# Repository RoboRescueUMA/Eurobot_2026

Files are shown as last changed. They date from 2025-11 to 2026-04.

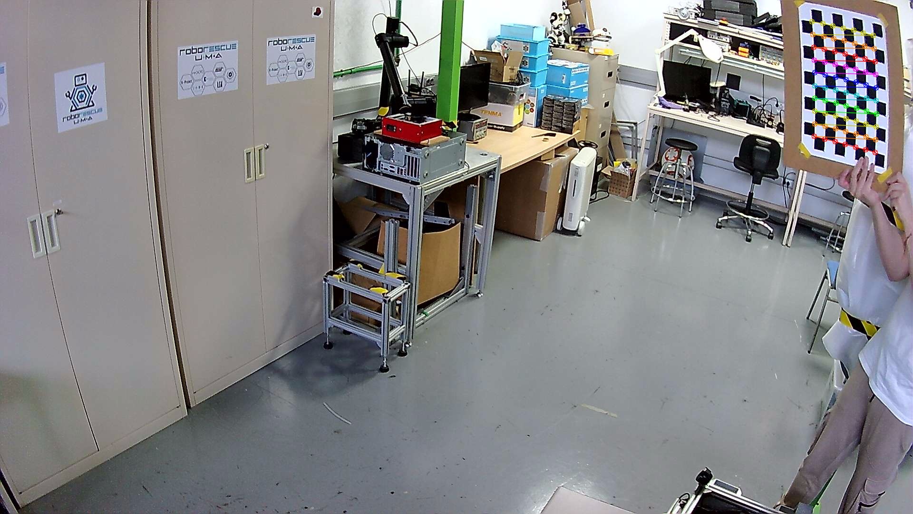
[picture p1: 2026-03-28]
Software/Visión Arucos/fotos_calibracion_detectadas2/foto_037.jpg

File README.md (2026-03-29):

# 🤖 Eurobot 2026 — RoboRescue Team

Repositorio oficial del equipo **RoboRescue** para la competición **Eurobot 2026**.

---

## 🧠 ¿Qué es Eurobot?

**Eurobot** es una competición internacional de robótica donde equipos diseñan, construyen y programan robots autónomos capaces de realizar tareas en un entorno de juego específico.

Cada año, la competición propone un nuevo desafío con reglas propias, donde los robots deben:
* Actuar de forma completamente autónoma
* Interactuar con elementos del entorno
* Competir contra otro robot en tiempo real
* Maximizar la puntuación en un tiempo limitado

---
## 🧊 Eurobot 2026 — “Winter is Coming”
El objetivo general del juego es ayudar a unas ardillas a recuperar y proteger sus bellotas antes de que vuelvan los humanos, gestionando misiones como recuperar 
cajas, controlar condiciones ambientales o devolverlas a sus nidos antes de tiempo.

* Para más información sobre la competicion leer --> Reglamento / EurobotSenior_General.pdf

---

## 🧩 Estructura del Repositorio

El proyecto está organizado en varios módulos principales:

```
📂 Eurobot_2026
├── ⚙️ hardware/                           # Diseño mecánico y 3D, esquemas electrónicos y slprt de componentes
├── 🧠 software/                           # Código del robot (ROS2, control, visión, etc.)
├── 📄 reglamento/                         # Documentación técnica
└── 📦 documentos de referencia/           # Documentos que pueden ser de ayuda
```

---

## ⚙️ Arquitectura del Sistema

El robot sigue una arquitectura distribuida:

### 🔹 Nivel Alto (Computación)

* Procesamiento de visión
* Planificación de trayectoria
* Toma de decisiones

### 🔹 Nivel Bajo (Control en Tiempo Real)

* Lectura de sensores
* Control de motores

### 🔹 Comunicación

* Middleware basado en **ROS 2**
* Intercambio de datos entre nodos

---

## 🚀 Tecnologías Utilizadas

* **ROS 2** → Comunicación entre nodos
* **Python / C++** → Desarrollo de software
* **ESP32** → Control de hardware
* **OpenCV** → Visión artificial
* **CAD (SolidWorks)** → Diseño mecánico

---

## 🏁 Estado del Proyecto

🚧 En desarrollo — Temporada Eurobot 2026

---

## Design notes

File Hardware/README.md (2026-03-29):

# 🤖 Eurobot 2026 — Hardware & Design

Aquí se centralizan todos los archivos de **diseño físico**, **electrónica** y **modelado 3D** del robot para la competición **Eurobot 2026**.

---

## 📂 Estructura del Repositorio

La sección de Hardware se divide en **tres pilares fundamentales**:

---

### ⚙️ 1. Componentes

Contiene las librerías de piezas individuales y activos estándar utilizados en el ensamblaje.

| 🔧 Categoría  | 📦 Contenido |
| --- | --- |
| 🤖 Motores | Modelos y soportes para **Servos**, motores y sistemas de garras |
| 📡 Sensores | Archivos para **HC-SR04** y **RPLidar C1** |
| 🧠 Control | Modelos de **Raspberry Pi** |
| 📦 Miscelánea | Baterías, rodamientos, microswitches y otros componentes auxiliares |

---

### ⚡ 2. Electrónica

Aquí se encuentra toda la electrónica y la distribución de potencia del robot.

| ⚡ Sección | 📄 Contenido |
| --- | --- |
| 🧩 Esquemas KiCad | Archivos del diseño eléctrico listo para modificarlo |
| 🔌 Esquema eléctrico | Referencia rápida del cableado y conexionado en formato PDF |

---

### 🏗️ 3. Modelos 3D

Ensamblajes principales y diseños mecánicos complejos del robot.

| 🏗️ Categoría | 📦 Contenido |
| --- | --- |
| 🚗 Chasis | Diseños del **Chasis** del Robot |
| 🦾 Mecanismos | Diseño de la **Garra** y sistema de elevación |
| 📦 Cajas | Diseños como **CajaBellota** |

---

## 🛠️ Herramientas Utilizadas

| 🧰 Tipo | 🔧 Herramientas |
| --- | --- |
| 🧱 CAD  | SolidWorks (`.SLDPRT`, `.SLDASM`) + formatos `.STEP` |
| ⚡ EDA | KiCad (diseño de circuitos impresos) |

---

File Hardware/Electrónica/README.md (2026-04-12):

# 🤖 Eurobot 2026 — Arquitectura Electrónica

**Diseño eléctrico, esquemas y documentación técnica** del sistema electrónico del robot desarrollado para la competición **Eurobot 2026**.

---

## 🧠 Arquitectura del Sistema

El robot implementa una **arquitectura híbrida de procesamiento**, donde la inteligencia de alto nivel y el control en tiempo real están separados para lograr robustez, velocidad y modularidad:

### 🔹 Nivel Superior — Visión & Estrategia

* **Raspberry Pi**
* Ejecuta:

  * Visión artificial
  * Planificación de alto nivel
  * Lógica de misión
  * Comunicación con sistemas de percepción

### 🔹 Nivel de Control — Tiempo Real & Actuación

* **ESP32**
* Responsable de:

  * Control de motores
  * Control de servos
  * Lectura de sensores
  * Odometría

### 🔗 Comunicación entre controladores

* Conexión **Serial / UART (TX-RX) por cable**
* Permite:

  * Baja latencia
  * Mayor robustez ante interferencias
  * Sin dependencias de red inalámbrica

---

## 🛠️ Componentes Principales

| Ítem | Componente | Cantidad | Función |
| ---- | --- | --- | --- |
| 1 | ESP32 | 1 | Control en tiempo real |
| 2 | Raspberry Pi 5 | 1 | Visión y lógica de misión |
| 3 | Driver Puente H DRI0002 | 2 | Control de motores DC |
| 4 | Motor DC + Encoder | 4 | Tracción y odometría |
| 5 | Regulador LM2596 | 1 | Conversión 12V → 5V |
| 6–8  | Servomotores | 3 | FT5335M, HS-331, sg90 |
| 10 | Seta de emergencia | 1 | Parada inmediata del sistema |

---

## 📐 Esquema Eléctrico

El diseño se ha realizado en **KiCad 9.0.6**.

* Entrada principal desde batería **12V nominal (≈11.6V real)**

---

## 🔌 Asignación de Pines — ESP32

### 🏎️ Tracción (Drivers)

| Pines ESP32 | Función | Motor / Driver |
| --- | --- | --- |
| 27 / 14 | PWM / DIR | Delantero Izquierdo (DR1) |
| 25 / 26 | PWM / DIR | Delantero Derecho (DR1) |
| 32 / 33 | PWM / DIR | Trasero Izquierdo (DR2) |
| 18 / 19 | PWM / DIR | Trasero Derecho (DR2) |

---

### 📊 Odometría (Encoders)

| Pines ESP32 | Canal | Encoder |
| --- | ----- | --- |
| 21 / 22 | A / B | Delantero Izquierdo |
| 34 / 35 | A / B | Delantero Derecho |
| 16 / 17 | A / B | Trasero Izquierdo |
| 23 / 4 | A / B | Trasero Derecho |

---

### 🦾 Manipulación (Servos)

| Pin Raspberry | Nombre GPIO |Elemento |
| --- | --- | --- |
| 12 | GPIO 18 | Servo 1 |
| 32 | GPIO 12 | Servo 2 |
| 33 | GPIO 13 | Servo 3 |
| 14 (o cualquier GND) | Ground | Tierra
| No Usado  | Input | Encoder Feedback Elevación |
| ND. | ND. | Microswitch detección piezas|

---

## 🏁 Arranque (microswitch)

| Pines Raspberry | 
| -----------  |
| ND      |
| GND     |

---

## 🛡️ Seguridad y Operación

* 🛑 **Parada de emergencia** mediante seta física que corta alimentación general.
* 🧵 **Arranque con cuerda** para iniciar el ciclo de competición.

---

> ⚡ Este repositorio es parte del desarrollo del robot para la competición Eurobot 2026.

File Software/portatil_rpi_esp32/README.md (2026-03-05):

# Robot Eurobot 2026 - Equipo RoboRescue

Proyecto de robot autónomo para la competición **Eurobot 2026** - Categoría Senior.

**Equipo:** RoboRescue

---

## Descripción del Proyecto

Este proyecto implementa un robot autónomo con arquitectura distribuida para competir en Eurobot 2026. El sistema está dividido en tres componentes principales:

- **Portátil**: Procesamiento intensivo de visión por computadora
- **Raspberry Pi 4**: Coordinación, navegación y control de alto nivel
- **ESP32**: Control de bajo nivel de motores y actuadores

### Características Principales

- 🤖 Robot con **ruedas Mecanum** para movimiento omnidireccional
- 👁️ **Sistema de visión distribuida** con detección de **ArUco markers**
- 🎯 **Navegación autónoma** con control proporcional
- 🔗 Comunicación distribuida mediante **ROS2 Humble**
- ⚡ Control de motores con **micro-ROS** en ESP32
- 📍 Localización precisa mediante cámara zenital (IP Camera)
- 🔄 **Arquitectura de 3 capas:** Laptop (visión) → RPI4 (relay) → ESP32 (motores)

---

## Estructura del Proyecto

```
laptop_rpi_esp/
├── docs/                         # Documentación del proyecto
│   ├── guias/                   # Guías de uso
│   │   ├── GUIA_VISION_DISTRIBUIDA.md    # Sistema de visión con ArUco
│   │   ├── GUIA_PRUEBAS_ROBOT.md         # Comandos de prueba
│   │   └── INSTALACION_DEPENDENCIAS.md   # Dependencias externas
│   ├── troubleshooting/         # Solución de problemas
│   │   ├── encoders.md          # Problemas con encoders
│   │   ├── micro-ros.md         # Problemas con micro-ROS
│   │   ├── esp32-flash.md       # Problemas subiendo código a ESP32
│   │   └── motores.md           # Problemas con motores
│   ├── hardware/                # Especificaciones técnicas
│   │   ├── ESPECIFICACIONES_HARDWARE.md
│   │   └── CONEXION_ENCODERS.md
│   ├── architecture/            # Diagramas de arquitectura
│   │   └── ARQUITECTURA_SISTEMA.md
│   └── reglamento/              # Reglamento oficial Eurobot 2026
│       ├── EurobotSenior_general.pdf
│       ├── Arena y puntuaciones.pdf
│       └── RESUMEN_REGLAMENTO.md
├── src/                         # Paquetes ROS2
│   ├── robot_localization/     # 🆕 Localización + Navegación (Laptop)
│   │   ├── robot_localization/
│   │   │   ├── camera_publisher.py        # Captura de cámara IP cenital
│   │   │   ├── field_localizer.py         # Detección ArUco + Homografía (poses absolutas)
│   │   │   └── aruco_navigator.py (futura) # Navegación en campo (por implementar)
│   │   ├── launch/
│   │   │   └── robot_localization.launch.py
│   │   ├── config/
│   │   │   └── robot_localization.yaml
│   │   ├── package.xml
│   │   └── setup.py
│   ├── laptop_vision/          # (Antiguo - mantener como referencia histórica)
│   │   └── (código anterior de visión relativa)
│   ├── rpi_relay/              # 🆕 Relay de comandos (RPI4)
│   │   └── cmd_vel_relay.py         # Reenvía /roborescue/cmd_vel_laptop → /roborescue/cmd_vel
│   ├── robot_vision/           # (Antiguo - backup)
│   ├── robot_navigator/        # (Antiguo - backup)
│   └── interfaces/             # Mensajes y servicios personalizados (TODO)
├── esp32_roborescue/           # ESP32 robot competición (DFRobot drivers)
│   ├── src/main.cpp            # Control Mecanum con PWM+DIR
│   └── README.md               # Documentación específica
├── esp32_casa/                  # ESP32 robot pruebas (L298N drivers)
│   ├── src/main.cpp            # Control Mecanum con IN1/IN2+EN
│   └── README.md               # Documentación específica
├── config/                      # Archivos de configuración
├── launch/                      # Launch files centralizados
└── README.md                    # Este archivo
```

---

## Requisitos del Sistema

### Hardware

- **Portátil** con WiFi (Ubuntu 22.04 recomendado)
- **Raspberry Pi 4** (4GB RAM o superior)
- **ESP32** (DevKit o similar)
- **4x Motores DC** con encoders y reductora
- **2x Puentes H** (drivers DFRobot o equivalentes)
- **4x Ruedas Mecanum** (omni-direccionales)
- **Cámara IP** (WiFi/Ethernet, HD)
- **Marcadores ArUco** (DICT_4X4_50)
- Batería LiPo con protección (máx. 48V según reglamento)

### Software

- **ROS2 Humble** (Ubuntu 22.04)
- **Python 3.10+** con OpenCV, NumPy
- **PlatformIO** (para ESP32)
- **micro-ROS** (para comunicación ESP32-ROS2)

### Configuración del Sistema

- **ROS_DOMAIN_ID:** 17 (evita conflictos con otros robots)
- **Namespace:** `roborescue`
- **Cámara IP:** `10.16.250.84:5000`
- **Sistema de Localización:** Homografía con 4 ArUcos fijos en esquinas del campo
- **ArUco IDs (Fijos - Campo):**
  - Esquina sup-izq: 20 → (0, 0) cm
  - Esquina sup-der: 21 → (300, 0) cm
  - Esquina inf-izq: 22 → (0, 200) cm
  - Esquina inf-der: 23 → (300, 200) cm
- **ArUco IDs (Móviles):**
  - Robot: 1
  - Caja azul: 36
  - Caja amarilla: 47
- **Diccionario ArUco:** DICT_4X4_50
- **Tamaño campo:** 300 cm × 200 cm (Eurobot 2026)

### Parámetros de Navegación (Actuales)

- **max_linear_speed:** 0.25 m/s
- **max_angular_speed:** 0.5 rad/s
- **linear_p_gain:** 2.5 (necesario para generar velocidad > PWM_MIN)
- **angular_p_gain:** 0.6
- **Histéresis angular:**
  - Umbral entrar: 20° (entra en modo rotación)
  - Umbral salir: 10° (sale de modo rotación)
- **goal_tolerance:** 0.20 m (distancia de parada al objetivo)
- **PWM_MIN:** 80 (~0.31 m/s - necesario para vencer fricción estática)
- **Encoders:** Habilitados (11 PPR motor × 34 reducción = 374 PPR rueda, cuadratura ×4 = 1496 counts/rev)

---

## Instalación

### 1. Configurar ROS2 Workspace (Portátil y Raspberry Pi)

```bash
# Instalar ROS2 Humble (si no está instalado)
# Ver: https://docs.ros.org/en/humble/Installation.html

# Clonar el repositorio
cd ~/Desktop/GitHub
git clone <URL_DEL_REPOSITORIO> pruebas_eurobot
cd pruebas_eurobot

# Instalar dependencias de Python y OpenCV
sudo apt update
sudo apt install python3-pip python3-opencv ros-humble-cv-bridge

# Instalar dependencias de Python adicionales
pip3 install opencv-python numpy

# Compilar workspace
colcon build --packages-select laptop_vision rpi_relay
source install/setup.bash
```

**Nota:** Ver `docs/guias/INSTALACION_DEPENDENCIAS.md` para detalles completos de todas las dependencias externas.

### 2. Configurar micro-ROS en Raspberry Pi

#### Opción A: Instalar micro-ROS Agent (solo agent)

```bash
# Instalar micro-ROS agent desde paquetes binarios
sudo apt install ros-humble-micro-ros-agent

# Ejecutar agent (ajustar puerto serial)
ros2 run micro_ros_agent micro_ros_agent serial --dev /dev/ttyUSB0 -b 115200
```

#### Opción B: Compilar micro_ros_setup (completo, requerido para desarrollo ESP32)

```bash
# Crear workspace separado para micro-ROS
mkdir -p ~/ros2_ws/src
cd ~/ros2_ws/src

# Clonar micro_ros_setup
git clone -b humble https://github.com/micro-ROS/micro_ros_setup.git

# Compilar
cd ~/ros2_ws
colcon build --packages-select micro_ros_setup
source install/setup.bash

# Ejecutar agent
ros2 run micro_ros_agent micro_ros_agent serial --dev /dev/ttyUSB0 -b 115200
```

**Importante:** Si vas a compilar firmware para ESP32, necesitas usar la Opción B.

### 3. Flashear ESP32 (desde cualquier máquina con PlatformIO)

#### Robot RoboRescue (Universidad - Competición):
```bash
cd esp32_roborescue/
# Editar platformio.ini si es necesario
pio run --target upload
```

#### Robot Casa (Pruebas personales):
```bash
cd esp32_casa/
# Editar platformio.ini si es necesario
pio run --target upload
```

**Nota:** Ver README.md en cada carpeta ESP32 para detalles específicos de hardware.

---

## Uso

### Sistema de Localización y Navegación (NUEVO - Recomendado)

Este es el sistema actual que implementa **localización absoluta en el campo** mediante homografía con 4 ArUcos fijos en las esquinas, seguida de **navegación autónoma** hacia objetivos.

#### En Portátil (Sistema de Localización):

```bash
cd ~/Desktop/GitHub/pruebas_eurobot
source install/setup.bash

# IMPORTANTE: Configurar ROS_DOMAIN_ID=17
export ROS_DOMAIN_ID=17

# Lanzar: Publicador de cámara IP + Localizador de campo con homografía
ros2 launch robot_localization robot_localization.launch.py \
  camera_ip:=10.16.250.84:5000

# Ver imagen con detecciones en tiempo real
ros2 run rqt_image_view rqt_image_view /roborescue/zenital/debug
```

**Ver:** `docs/guias/GUIA_ROBOT_LOCALIZATION.md` para guía detallada de la homografía y localización absoluta.

#### En Raspberry Pi 4 (Relay + micro-ROS):

```bash
cd ~/Desktop/GitHub/pruebas_eurobot
source install/setup.bash

# IMPORTANTE: Configurar ROS_DOMAIN_ID=17
export ROS_DOMAIN_ID=17

# Terminal 1: Micro-ROS Agent (comunicación con ESP32)
ros2 run micro_ros_agent micro_ros_agent serial --dev /dev/ttyUSB0 -b 115200

# Terminal 2: Relay de comandos (reenvía /roborescue/cmd_vel_laptop → /roborescue/cmd_vel)
ros2 run rpi_relay cmd_vel_relay
```

---

### Sistema Anterior - Visión Relativa (Backup)

#### 📍 Marcadores ArUco - Configuración Nuevo Sistema

El sistema de localización detecta posiciones **absolutas en el campo** usando 4 ArUcos fijos como referencia.

**Marcadores fijos (esquinas del campo):**
- **ID=20** - Esquina superior-izquierda (origen: 0, 0 cm)
- **ID=21** - Esquina superior-derecha (300, 0 cm)
- **ID=22** - Esquina inferior-izquierda (0, 200 cm)
- **ID=23** - Esquina inferior-derecha (300, 200 cm)

**Marcadores móviles:**
- **ID=1** - Robot (se detecta en coordenadas absolutas del campo)
- **ID=36** - Caja azul (coordenadas absolutas)
- **ID=47** - Caja amarilla (coordenadas absolutas)

**Colocación correcta:**

1. **Los 4 ArUcos fijos** deben estar colocados en las esquinas del campo de forma que:
   - El área vista por la cámara zenital es la del campo (300×200 cm)
   - Los 4 ArUcos están claramente visibles desde el inicio

2. **El ArUco del robot (ID=1)** debe estar:
   - Alineado de forma que su esquina 0 apunte hacia **adelante del robot**
   - Esto se visualiza en el debug como una flecha/círculo rojo que marca la dirección
   - La orientación se publica en `theta` (en grados) del topic `/roborescue/robot_pose`

**Verificación:**
- En la imagen debug (`/roborescue/zenital/debug`), deberías ver:
  - Los 4 ArUcos fijos etiquetados como "F20", "F21", "F22", "F23"
  - El ArUco del robot etiquetado como "ROBOT" con posición en cm y ángulo
  - Las cajas etiquetadas como "AZUL" y "AMARILLA" con posiciones absolutas

---

### Sistema Anterior (Backup)

Los paquetes `laptop_vision`, `robot_vision` y `robot_navigator` son versiones anteriores del sistema que usaban **visión relativa** (posiciones relativas al robot, no absolutas en el campo).

#### En Raspberry Pi 4:

```bash
# Terminal 1: Micro-ROS Agent
ros2 run micro_ros_agent micro_ros_agent serial --dev /dev/ttyUSB0

# Terminal 2: Navegación y control
ros2 launch robot_navigator eurobot_launch.py
```

#### En Portátil:

```bash
# Terminal 1: Procesamiento de visión
ros2 launch laptop_vision laptop_vision.launch.py camera_ip:=10.16.250.84:5000 target:=blue_box

# Terminal 2: Monitoreo (opcional)
ros2 run rqt_image_view rqt_image_view
```

---

### Verificar Comunicación

```bash
# Ver topics activos
ros2 topic list

# Monitorear comandos de velocidad
ros2 topic echo /roborescue/cmd_vel

# Ver posiciones ABSOLUTAS detectadas (nuevo sistema)
ros2 topic echo /roborescue/robot_pose         # X, Y en cm, theta en grados
ros2 topic echo /roborescue/blue_box_pose
ros2 topic echo /roborescue/yellow_box_pose

# Ver imágenes procesadas
ros2 run rqt_image_view rqt_image_view /roborescue/zenital/debug
```

---

### Verificar Encoders

```bash
# Ver velocidades de encoders (FL, FR, RL, RR en RPM)
export ROS_DOMAIN_ID=17
ros2 topic echo /roborescue/encoder_velocities
```

**Ver guía completa de pruebas:** `docs/hardware/CONEXION_ENCODERS.md`  
**Troubleshooting:** `docs/troubleshooting/encoders.md`

---

## Arquitectura del Sistema

```
┌─────────────────────────────────────────────────────────────────────────────┐
│                    ARQUITECTURA DISTRIBUIDA - 3 CAPAS                        │
└─────────────────────────────────────────────────────────────────────────────┘

  ┌─────────────────────┐        ┌─────────────────────┐        ┌──────────────────┐
  │   PORTÁTIL (WiFi)   │        │   RPI4 (Ethernet)   │        │  ESP32 (Serial)  │
  │                     │        │                     │        │                  │
  │  robot_localization │        │   rpi_relay         │        │  micro-ROS       │
  │  ├─ camera_pub      │        │   ├─ cmd_vel_relay  │        │  ├─ Cinemática   │
  │  └─ field_local     │        │   │    (relay with   │        │  │   Mecanum      │
  │     (homografía     │        │   │    namespace)    │        │  └─ Control PWM  │
  │      poses abs)     │  ROS2  │   └─────────┬───────┼────────┼──────PWM_MIN=80──►
  │                     │  WiFi  │             │       │ Serial │                  │
  │  Publicadores:      │  DDS   │  /roborescue│       │ micro- │   Suscriptor:    │
  │  /roborescue/       │        │  /cmd_vel_  │       │  ROS   │  /roborescue/    │
  │    zenital/*        │        │   laptop    │       │        │    cmd_vel       │
  │  /roborescue/       │        │      ↓      │       │        │                  │
  │    *_pose (ABS)     │        │  /roborescue│       │        │                  │
  │  /roborescue/       │        │   /cmd_vel  │       │        │                  │
  │    cmd_vel_laptop   │        └─────────────┘       │        └────────┬─────────┘
  └──────────┬──────────┘        └─────────────┘       │                 │
             │                                         │                 │
      Cámara IP (móvil)                         micro_ros_agent    4x Motores DC
      Homografía + ArUcos                       (ROS2↔micro-ROS)   + 2x Drivers
      (10.16.250.84:5000)                       bridge process     (Ruedas Mecanum)

NUEVO: Coordenadas ABSOLUTAS del campo (cm)
       - Origen: esquina sup-izq (ArUco 20)
       - X+ = derecha, Y+ = abajo
       - 4 ArUcos fijos en esquinas (IDs 20-23)
```

### Flujo de Datos Completo

1. **Cámara IP** (móvil con IPCamera app) → Stream video vía WiFi
2. **Portátil** recibe stream → `camera_publisher` publica en `/roborescue/zenital/image_raw`
3. **Portátil** `field_localizer` (NUEVO):
   - Detecta los 4 ArUcos fijos en las esquinas (IDs 20-23)
   - Calcula homografía píxeles → cm del campo
   - Transforma posiciones de robot y cajas a coordenadas ABSOLUTAS del campo
4. **Portátil** publica poses ABSOLUTAS:
   - `/roborescue/robot_pose` → X, Y en cm, theta en grados
   - `/roborescue/blue_box_pose`, `/roborescue/yellow_box_pose`
5. **Portátil** `aruco_navigator` (por implementar) → Recibirá poses absolutas, calculará velocidades
6. **Portátil** publica comandos → `/roborescue/cmd_vel_laptop` (Twist)
7. **RPI4** `cmd_vel_relay` reenvía → `/roborescue/cmd_vel_laptop` → `/roborescue/cmd_vel`
8. **ESP32** recibe vía micro-ROS → `/roborescue/cmd_vel` (Twist)
9. **ESP32** calcula cinemática inversa → Velocidades individuales de 4 ruedas Mecanum
10. **ESP32** envía PWM → 4 motores DC → Robot se mueve

### Topics ROS2 Principales

**Laptop publica (robot_localization):**
- `/roborescue/zenital/image_raw` - Video cámara (Image)
- `/roborescue/zenital/image_raw/compressed` - Video comprimido (CompressedImage)
- `/roborescue/zenital/debug` - Video con anotaciones (Image)
- `/roborescue/robot_pose` - **Posición ABSOLUTA en cm + orientación en grados** (Pose2D: x, y, theta)
- `/roborescue/blue_box_pose` - **Posición ABSOLUTA en cm + orientación** (Pose2D)
- `/roborescue/yellow_box_pose` - **Posición ABSOLUTA en cm + orientación** (Pose2D)
- `/roborescue/cmd_vel_laptop` - Comandos de velocidad (Twist) [por implementar: aruco_navigator]

**RPI4 relay:**
- Suscribe: `/roborescue/cmd_vel_laptop` (Twist)
- Publica: `/roborescue/cmd_vel` (Twist) - Para ESP32 vía micro-ROS

**ESP32 suscribe:**
- `/roborescue/cmd_vel` (Twist) - Velocidades lineales (x, y) y angular (z)

---

## Documentación Adicional

### Documentación Adicional

### Documentación del Sistema

- 📍 [**Guía de Localización Absoluta (Homografía)**](docs/guias/GUIA_ROBOT_LOCALIZATION.md) - **NUEVO**: Sistema con coordenadas absolutas del campo
- 👁️ [**Guía del Sistema de Visión Distribuida**](docs/guias/GUIA_VISION_DISTRIBUIDA.md) - Sistema anterior (visión relativa)
- 📦 [**Instalación de Dependencias**](docs/guias/INSTALACION_DEPENDENCIAS.md) - Guía completa de dependencias externas
- 🧪 [**Guía de Pruebas**](docs/guias/GUIA_PRUEBAS_ROBOT.md) - Comandos de prueba para Robot Casa y RoboRescue
- 🔧 [**Troubleshooting**](docs/troubleshooting/) - Problemas comunes y soluciones por categoría
  - [Encoders](docs/troubleshooting/encoders.md)
  - [micro-ROS](docs/troubleshooting/micro-ros.md)
  - [ESP32 Flash](docs/troubleshooting/esp32-flash.md)
  - [Motores](docs/troubleshooting/motores.md)

### Documentación del Proyecto

- 📖 [Resumen del Reglamento Eurobot 2026](docs/reglamento/RESUMEN_REGLAMENTO.md)
- 🔩 [Especificaciones de Hardware](docs/hardware/ESPECIFICACIONES_HARDWARE.md)
- 🏗️ [Arquitectura del Sistema](docs/architecture/ARQUITECTURA_SISTEMA.md)

### Documentación del Hardware

- 🤖 [ESP32 RoboRescue](esp32_roborescue/README.md) - Robot de competición (DFRobot drivers)
- 🏠 [ESP32 Casa](esp32_casa/README.md) - Robot de pruebas (L298N drivers)

---

## Calendario y Tareas Pendientes

### Fechas Importantes (Verificar con organizador)

- ✅ Inscripción del equipo
- ⚠️ **Logo del equipo** - Fecha límite: TBD
- ⚠️ **Video de presentación** - Fecha límite: 10 de Febrero
- ⚠️ **Homologación del robot** - Fecha límite: 1 de Marzo
- ⚠️ **Póster técnico y presentación** - Fecha límite: 1 de Marzo
- 🎯 **Robot montado (hardware)** - Fecha límite: 20 de Febrero
- 🎯 **Software básico funcional** - Fecha límite: 15 de Marzo
- 🎯 **Pruebas en escenario** - Fecha límite: 15 de Abril
- 🏁 **Competición Nacional** - Abril 2026

### Próximos Pasos Técnicos

#### ✅ Completados

- [x] **Sistema de visión distribuida funcional** - Laptop (visión) → RPI4 (relay) → ESP32 (motores)
- [x] **Detección de ArUco markers** - DICT_4X4_50 con auto-calibración de escala
- [x] **Navegación autónoma básica** - Control proporcional hacia cajas azul/amarilla (ambas probadas)
- [x] **Timeout de seguridad** - Robot se detiene automáticamente sin detección (1s)
- [x] **Cámara IP funcional** - Streaming desde móvil con app IPCamera
- [x] **Namespace correcto en ROS2** - Topics organizados bajo `/roborescue/`
- [x] **Comunicación RPI ↔ Laptop** - ROS2 DDS sobre WiFi/Ethernet
- [x] **Relay de comandos en RPI** - `/roborescue/cmd_vel_laptop` → `/roborescue/cmd_vel`
- [x] **Conexión ESP32 ↔ RPI (micro-ROS)** - Serial /dev/ttyUSB0 con namespace funcionando
- [x] **Integración completa 3 capas** - Sistema end-to-end probado exitosamente
- [x] **Control de motores desde visión** - Robot se mueve según detección ArUco
- [x] **Calibración PWM para fricción** - PWM_MIN=80 permite vencer fricción estática
- [x] **Inversión de coordenadas 180°** - Sistema funciona con cámara rotada 180°
- [x] **Movimiento omnidireccional** - Navegación con strafing lateral funcional
- [x] **Ajuste de ganancias proporcionales** - linear_p_gain=2.5, angular_p_gain=0.6

#### 🔄 En Progreso

- [ ] **Implementar aruco_navigator dentro de robot_localization** - Navegación hacia objetivos usando poses absolutas
- [ ] **Pruebas en arena de competición** - Validar navegación en superficie plana de competencia
- [ ] **Filtrado de posiciones ArUco** - Aplicar promedio móvil para reducir jitter de detección

#### 📋 Pendientes

- [ ] **Mejorar cálculo de distancia** - Usar distancia 2D proyectada (ignorar diferencia de altura ArUco)
- [ ] **Optimizar control cerca del objetivo** - Reducir PWM_MIN o implementar mapeo proporcional
- [ ] **Control PID completo** - Añadir términos I y D para mejor estabilidad

---

## Referencias del Proyecto Antiguo

El código base proviene de proyectos anteriores:

- **ROS2 Workspace:** `/home/maki/Desktop/rpi_casa/src/`
  - `robot_vision/` - Detección ArUco y seguimiento
  - `robot_navigator/` - Control de navegación
  
- **ESP32 micro-ROS:** `/home/maki/Documents/PlatformIO/Projects/microros_esp_eurobot/`
  - Control de motores Mecanum funcional

---

## Contribuir

Este es un proyecto de equipo para Eurobot 2026.

### Workflow de Desarrollo

1. Crear rama para nueva funcionalidad: `git checkout -b feature/nombre`
2. Desarrollar y probar localmente
3. Commit con mensajes descriptivos
4. Push y crear pull request para revisión
5. Integrar tras aprobación del equipo

---

## Recursos Externos

- 🌐 [Sitio oficial Eurobot](https://www.eurobot.org/)
- 📚 [FAQ Eurobot](https://www.eurobot.org/faq/)
- 📧 Comité de árbitros: referee@eurobot.org
- 🤖 [Documentación ROS2 Humble](https://docs.ros.org/en/humble/)
- 🔌 [micro-ROS Documentation](https://micro.ros.org/)

---

## Licencia

Por definir por el equipo.

---

## Equipo

**Nombre del equipo:** RoboRescue  
**Año:** 2026  
**Categoría:** Senior

**Miembros:**
- [Completar]

---

## Robots del Proyecto

### Robot RoboRescue (Universidad - Competición)
- **Ubicación código:** `esp32_roborescue/`
- **Hardware:** 4x Ruedas Mecanum + 2x DFRobot drivers
- **Estado:** Listo para competición
- **Uso:** Eurobot 2026 oficial

### Robot Casa (Pruebas personales)
- **Ubicación código:** `esp32_casa/`
- **Hardware:** Preparado para Mecanum + 2x L298N drivers
- **Estado:** En desarrollo
- **Uso:** Pruebas y desarrollo de software

---

**Última actualización:** Febrero 18, 2026

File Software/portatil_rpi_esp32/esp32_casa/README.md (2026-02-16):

# ESP32 - Robot de Pruebas (Casa)

## Descripción
Este es el código para el **robot de pruebas personal** con ruedas preparadas para Mecanum.

---

## Características del Robot

### Hardware
- **Ruedas:** Preparado para 4x Mecanum (código listo aunque aún sin ruedas físicas)
- **Configuración:** X-Drive
- **Drivers:** 2x L298N (puente H clásico)
- **Control:** IN1/IN2/IN3/IN4 (dirección) + ENA/ENB (velocidad PWM)

### Especificaciones Técnicas
- **Movimiento:** Omnidireccional cuando tengas las ruedas Mecanum
- **Control:** Via micro-ROS (igual que RoboRescue)
- **Topic:** `/cmd_vel` (geometry_msgs/Twist)

---

## Configuración de Pines

### Driver 1 (Trasero) - L298N

| Motor | Ubicación | ENA/ENB | IN1 | IN2 | Canal PWM |
|---|---|---|-----|-----|---|
| M0 | Trasero Izquierda | GPIO32 | GPIO33 | GPIO25 | Canal 0 |
| M1 | Trasero Derecha | GPIO14 | GPIO26 | GPIO27 | Canal 1 |

### Driver 2 (Frontal) - L298N

| Motor | Ubicación | ENA/ENB | IN1 | IN2 | Canal PWM |
|---|---|---|-----|-----|---|
| M2 | Frontal Izquierda | GPIO15 | GPIO2 | GPIO4 | Canal 2 |
| M3 | Frontal Derecha | GPIO5 | GPIO18 | GPIO19 | Canal 3 |

**Nota:** Motor 3 usa GPIO18/19 (antes 16/17) para evitar conflictos con UART2.

---

## Lógica de Control

### Driver L298N (IN1/IN2 + EN)

```cpp
// Para cada motor:
IN1=HIGH, IN2=LOW → Adelante
IN1=LOW, IN2=HIGH → Atrás
IN1=LOW, IN2=LOW → Freno
ENA/ENB (PWM 0-255) → Velocidad
```

### Cinemática Mecanum (X-Drive)

```cpp
// Mismo algoritmo que RoboRescue
// Entradas: vx, vy, wz
fl = vx - vy - wz  // Frontal Izquierda (M2)
fr = vx + vy + wz  // Frontal Derecha (M3)
rl = vx + vy - wz  // Trasera Izquierda (M0)
rr = vx - vy + wz  // Trasera Derecha (M1)
```

---

## Diferencias con RoboRescue

| Característica | RoboRescue (Universidad) | Casa (Pruebas) |
|---|---|---|
| Driver | DFRobot (PWM+DIR) | L298N (IN1/IN2+EN) |
| Pines por motor | 2 (PWM, DIR) | 3 (IN1, IN2, EN) |
| Lógica control | DIR=HIGH→Adelante | IN1=HIGH,IN2=LOW→Adelante |
| Ruedas físicas | ✅ Mecanum instaladas | ⚠️ Pendiente de instalar |

---

## Compilar y Flashear

```bash
cd ~/Desktop/laptop_rpi_esp/esp32_casa
pio run --target upload
```

### Monitor Serial

```bash
pio device monitor
```

---

## Conectar con ROS2

### Desde tu portátil o RPI:

```bash
# Importante: Configurar Domain ID 17
export ROS_DOMAIN_ID=17

# Iniciar micro-ROS agent
ros2 run micro_ros_agent micro_ros_agent serial --dev /dev/ttyUSB0 -b 115200
```

### Probar movimiento:

```bash
# IMPORTANTE: Los comandos van al namespace roborescue
export ROS_DOMAIN_ID=17

# Mover adelante
ros2 topic pub /roborescue/cmd_vel geometry_msgs/Twist "{linear: {x: 0.3, y: 0.0, z: 0.0}, angular: {x: 0.0, y: 0.0, z: 0.0}}"

# Mover lateral (Mecanum)
ros2 topic pub /roborescue/cmd_vel geometry_msgs/Twist "{linear: {x: 0.0, y: 0.3, z: 0.0}, angular: {x: 0.0, y: 0.0, z: 0.0}}"

# Girar
ros2 topic pub /roborescue/cmd_vel geometry_msgs/Twist "{linear: {x: 0.0, y: 0.0, z: 0.0}, angular: {x: 0.0, y: 0.0, z: 0.5}}"
```

---

## Seguridad

### Zona Muerta
- PWM < 20 → PWM = 0 (evita zumbidos y sobrecalentamiento)

### Nodo micro-ROS
- Nombre del nodo: `esp32_casa_mecanum`
- Namespace: `roborescue`
- Domain ID: `17`
- Suscripción: `/roborescue/cmd_vel`
- Watchdog: Parada automática tras 0.5s sin comandos

---

## Notas Importantes

- ⚠️ **El código está preparado para Mecanum** pero funcionará con ruedas normales (solo se ignorará el movimiento lateral)
- Cuando instales las ruedas Mecanum, el código ya está listo para usarlas sin cambios
- Si tienes problemas con los pines, verifica el pinout específico de tu ESP32
- **Motor 3 cambió de GPIO16/17 a GPIO18/19** para evitar problemas con UART2 (pins RX2/TX2)
- GPIO18/19 son más confiables para control de motores sin restricciones

---

## Historial de Cambios

### 2026-02-14
- **Actualización mayor:** Sincronización completa con esp32_roborescue
  - ✅ Añadido Domain ID 17 (igual que RPI y Laptop)
  - ✅ Añadido namespace "roborescue"
  - ✅ Implementado watchdog de seguridad (0.5s timeout)
  - ✅ Cinemática Mecanum X-Drive confirmada y documentada
  - ✅ Nombre de nodo actualizado: `esp32_casa_mecanum`
  - ✅ Topic actualizado: `/roborescue/cmd_vel`

### 2026-02-07
- **Motor 3 (Frontal Derecha):** Cambiado de GPIO16/17 a GPIO18/19
  - **Razón:** GPIO16 causaba fallo en retroceso (posible conflicto con UART2)
  - **Solución:** GPIOs 18/19 son de propósito general sin restricciones
  - **Acción requerida:** Reconectar cables IN3→GPIO18, IN4→GPIO19

---

## TODO (Cuando lleguen las Mecanum)

- [ ] Instalar las 4 ruedas Mecanum
- [ ] Verificar orientación correcta de las ruedas
- [ ] Calibrar direcciones de motores (puede que necesites invertir alguno)
- [ ] Probar movimiento omnidireccional
- [ ] Ajustar parámetros de normalización si es necesario

---

**Uso:** Pruebas personales y desarrollo  
**Última actualización:** Febrero 2026

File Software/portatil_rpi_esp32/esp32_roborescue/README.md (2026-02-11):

# ESP32 - Robot RoboRescue (Universidad)

## Descripción
Este es el código para el **robot de la competición Eurobot 2026** del equipo **RoboRescue**.

---

## Características del Robot

### Hardware
- **Ruedas:** 4x Mecanum (omni-direccionales)
- **Configuración:** X-Drive
- **Drivers:** 2x Puente H DFRobot
- **Control:** PWM + DIR por motor

### Especificaciones Técnicas
- **Movimiento:** Omnidireccional (X, Y, rotación)
- **Control:** Via micro-ROS desde Raspberry Pi 4
- **Topic:** `/cmd_vel` (geometry_msgs/Twist)

---

## Configuración de Pines

### Driver 1 (Trasero)

| Motor | Ubicación | PWM Pin | DIR Pin | Canal PWM |
|---|---|---|---|---|
| RL | Trasero Izquierda | GPIO25 | GPIO26 | Canal 0 |
| RR | Trasero Derecha | GPIO27 | GPIO14 | Canal 1 |

### Driver 2 (Delantero)

| Motor | Ubicación | PWM Pin | DIR Pin | Canal PWM |
|---|---|---|---|---|
| FL | Frontal Izquierda | GPIO18 | GPIO19 | Canal 2 |
| FR | Frontal Derecha | GPIO32 | GPIO33 | Canal 3 |

---

## Lógica de Control

### Driver DFRobot (PWM + DIR)

```cpp
// Para cada motor:
PWM (0-255) → Velocidad
DIR HIGH → Adelante
DIR LOW → Atrás
```

### Cinemática Mecanum (X-Drive)

```cpp
// Entradas: vx, vy, wz
fl = vx - vy - wz  // Frontal Izquierda
fr = vx + vy + wz  // Frontal Derecha
rl = vx + vy - wz  // Trasera Izquierda
rr = vx - vy + wz  // Trasera Derecha
```

---

## Compilar y Flashear

```bash
cd ~/Desktop/laptop_rpi_esp/esp32_roborescue
pio run --target upload
```

### Monitor Serial

```bash
pio device monitor
```

---

## Conectar con ROS2

### En Raspberry Pi 4:

```bash
# Iniciar micro-ROS agent (ajustar puerto si necesario)
ros2 run micro_ros_agent micro_ros_agent serial --dev /dev/ttyUSB0 -b 115200
```

### Probar movimiento:

```bash
# Mover adelante
ros2 topic pub /cmd_vel geometry_msgs/Twist "{linear: {x: 0.3, y: 0.0, z: 0.0}, angular: {x: 0.0, y: 0.0, z: 0.0}}"

# Mover lateral (izquierda)
ros2 topic pub /cmd_vel geometry_msgs/Twist "{linear: {x: 0.0, y: 0.3, z: 0.0}, angular: {x: 0.0, y: 0.0, z: 0.0}}"

# Girar
ros2 topic pub /cmd_vel geometry_msgs/Twist "{linear: {x: 0.0, y: 0.0, z: 0.0}, angular: {x: 0.0, y: 0.0, z: 0.5}}"
```

---

## Seguridad

### Watchdog
- Timeout: **500ms** sin recibir mensajes → Parar motores
- Zona muerta: PWM < 25 → PWM = 0

---

## Notas

- Este código está optimizado para los drivers DFRobot usados en el robot de competición
- Para el robot de pruebas casero, usar la carpeta `esp32_casa/`
- Asegurar que los cables están bien conectados según el pinout

---

**Equipo:** RoboRescue  
**Competición:** Eurobot 2026  
**Última actualización:** Febrero 2026

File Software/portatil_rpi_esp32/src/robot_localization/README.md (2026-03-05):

# robot_localization Package

## 📍 Descripción

El paquete **robot_localization** implementa un sistema de **localización absoluta y navegación autónoma** del robot en el campo usando:

- **4 marcadores ArUco fijos** en las esquinas del campo (referencia de posición)
- **Homografía 2D** para convertir coordenadas de píxeles de cámara a coordenadas del campo
- **Detección de ArUcos móviles** para rastrear el robot y objetos

**Sistema:** Cámara zenital → Detección ArUco → Homografía → Pose absoluta en el campo

---

## 🏗️ Estructura del Paquete

```
robot_localization/
├── robot_localization/          # Código fuente
│   ├── __init__.py
│   ├── camera_publisher.py      # Nodo: captura y publica frames de cámara IP
│   ├── field_localizer.py       # Nodo: detecta ArUcos y calcula homografía
│   └── aruco_navigator.py       # Nodo: (futuro) navega hacia coordenadas
├── launch/
│   └── robot_localization.launch.py  # Launch file para ambos nodos
├── config/
│   └── robot_localization.yaml  # Configuración: IDs ArUco, dimensiones campo
├── package.xml                  # Metadata del paquete
├── setup.py                     # Configuración Python
└── README.md                    # Este archivo
```

---

## 🚀 Compilación

```bash
# En la raíz del workspace
cd ~/Desktop/GitHub/pruebas_eurobot

# Compilar solo este paquete
colcon build --packages-select robot_localization

# Compilar y symlink (modo desarrollo)
colcon build --packages-select robot_localization --symlink-install

# Fuente el workspace
source install/setup.bash
```

---

## 🎯 Nodos Principales

### 1. **camera_publisher.py** — Publicación de Frames

**Propósito:** Capturar frames de una cámara IP y publicarlos como tópico ROS

**Tópico publicado:**
- `/roborescue/zenital/image_raw` — Frames crudos (sensor_msgs/Image)

**Parámetros (config/robot_localization.yaml):**
- `camera_ip` — IP de la cámara (ej: "192.168.1.100")
- `camera_port` — Puerto de la cámara (por defecto: 5000)
- `frame_rate` — FPS deseado (por defecto: 10 Hz)

**Ejecución:**
```bash
ros2 run robot_localization camera_publisher
```

---

### 2. **field_localizer.py** — Detección y Localización

**Propósito:** Detectar marcadores ArUco, calcular homografía y publicar posiciones absolutas

**Entrada:**
- `/roborescue/zenital/image_raw` — Frames de cámara

**Tópicos publicados:**
- `/roborescue/robot_pose` — Posición del robot: `Pose2D` (x, y en cm; theta en °)
- `/roborescue/blue_box_pose` — Posición caja azul (ArUco 36)
- `/roborescue/yellow_box_pose` — Posición caja amarilla (ArUco 47)
- `/roborescue/field_debug` — Debug: imagen con ArUcos dibujados

**Parámetros (config/robot_localization.yaml):**
```yaml
reference_markers:
  20: [0, 0]           # ArUco 20 → esquina (0, 0) del campo
  21: [300, 0]         # ArUco 21 → esquina (300, 0)
  22: [0, 200]         # ArUco 22 → esquina (0, 200)
  23: [300, 200]       # ArUco 23 → esquina (300, 200)

field_width_cm: 300    # Ancho del campo en cm
field_height_cm: 200   # Alto del campo en cm
```

**Ejecución:**
```bash
ros2 run robot_localization field_localizer
```

---

### 3. **aruco_navigator.py** — Navegación Autónoma (Futuro)

**Estado:** Todavía no implementado

**Propósito (cuando se implemente):**
- Suscribirse a waypoints o destinos
- Usar `field_localizer` para obtener posición actual
- Calcular comandos de movimiento para llegar al destino
- Publicar a `/roborescue/cmd_vel`

---

## 🎬 Lanzar Todo de Una Vez

```bash
# Opción 1: Con launch file (recomendado)
ros2 launch robot_localization robot_localization.launch.py

# Opción 2: Nodos individuales en diferentes terminales
# Terminal 1:
ros2 run robot_localization camera_publisher

# Terminal 2:
ros2 run robot_localization field_localizer
```

---

## 📊 Sistema de Coordenadas

```
(0, 0) -------- (300, 0)    Arriba (Y=0)
  │                │
  │   CAMPO        │
  │   300x200cm    │
  │                │
  └──────────────┘
(0, 200) ---- (300, 200)    Abajo (Y=200)

Izquierda          Derecha
(X=0)              (X=300)
```

**Unidades:**
- X, Y: centímetros (cm)
- θ (theta): grados (°), en rango [0°, 360°)
  - 0° = derecha (+X)
  - 90° = abajo (+Y)
  - 180° = izquierda (-X)
  - 270° = arriba (-Y)

---

## 🏷️ Marcadores ArUco

### Fijos (Referencia de Posición)

| ID | Posición (cm) | Ubicación |
|----|--|--|
| **20** | (0, 0) | Esquina superior izquierda |
| **21** | (300, 0) | Esquina superior derecha |
| **22** | (0, 200) | Esquina inferior izquierda |
| **23** | (300, 200) | Esquina inferior derecha |

### Móviles (Objetos Rastreados)

| ID | Objeto | Tópico publicado |
|----|---|--|
| **1** | Robot | `/roborescue/robot_pose` |
| **36** | Caja azul | `/roborescue/blue_box_pose` |
| **47** | Caja amarilla | `/roborescue/yellow_box_pose` |

---

## 📋 Requisitos

### Hardware
- Cámara IP con streaming MJPEG o H.264
- Conexión de red (Ethernet o Wi-Fi) desde RPI a cámara
- ArUcos impresos (6x6, diccionario DICT_6X6_250) de 8-10cm

### Software
- ROS2 Humble
- Python 3.10+
- OpenCV 4.5+ con módulo ArUco
- geometry_msgs (incluido en ROS2)

### Instalación de Dependencias

```bash
# Ubuntu/Debian
sudo apt update
sudo apt install -y python3-opencv python3-colcon-common-extensions

# ROS2 packages
sudo apt install -y ros-humble-cv-bridge ros-humble-image-transport
```

---

## 🔧 Configuración

### Archivo Principal: `config/robot_localization.yaml`

```yaml
# Identificadores de marcadores ArUco
reference_markers:
  20: [0, 0]
  21: [300, 0]
  22: [0, 200]
  23: [300, 200]

mobile_markers:
  1: "robot"
  36: "blue_box"
  47: "yellow_box"

# Dimensiones del campo (cm)
field_width_cm: 300
field_height_cm: 200

# Parámetros de cámara
camera_ip: "192.168.1.100"
camera_port: 5000
camera_topic_base: "zenital"

# Parámetros de detección
aruco_dict: "DICT_6X6_250"
min_marker_pixels: 50

# Parámetros de homografía
homography_update_frames: 30  # Recalcular H cada N frames
homography_ransac_threshold: 5.0
```

### Cambiar Configuración

**Opción A: Editar archivo YAML**
```bash
# Editar: src/robot_localization/config/robot_localization.yaml
# Cambiar valores, guardar, y relanzar nodos
```

**Opción B: Parámetros por línea de comandos**
```bash
ros2 run robot_localization field_localizer \
    --ros-args \
    -p field_width_cm:=400 \
    -p field_height_cm:=300
```

---

## 📊 Topología de Nodos y Topics

```
┌─────────────────────────────────────────────────────┐
│ Camera IP (Hardware)                                │
└─────────────────────┬───────────────────────────────┘
                      │ HTTP Stream
┌─────────────────────▼───────────────────────────────┐
│ camera_publisher (nodo)                             │
│ - Lee stream HTTP de cámara IP                      │
│ - Convierte a ROS Image message                     │
└─────────────────────┬───────────────────────────────┘
                      │
            /roborescue/zenital/
            image_raw (sensor_msgs/Image)
                      │
┌─────────────────────▼───────────────────────────────┐
│ field_localizer (nodo)                              │
│ - Detecta ArUcos en imagen                          │
│ - Calcula homografía de 4 referencias               │
│ - Transforma coordenadas a campo                    │
└─┬───────────┬──────────────────────┬────────────────┘
  │           │                      │
  │           │                      │
  ▼           ▼                      ▼
/roborescue/ /roborescue/         /roborescue/
robot_pose   blue_box_pose        yellow_box_pose
(Pose2D)     (Pose2D)             (Pose2D)
```

---

## 🧪 Testing y Debugging

### Verificar que Nodos Corren

```bash
# Ver nodos activos
ros2 node list
# Debería mostrar:
# /camera_publisher
# /field_localizer

# Ver topics
ros2 topic list
# Debería mostrar:
# /roborescue/zenital/image_raw
# /roborescue/robot_pose
# /roborescue/blue_box_pose
# /roborescue/yellow_box_pose
```

### Monitorear Poses en Tiempo Real

```bash
# Robot
ros2 topic echo /roborescue/robot_pose

# Caja azul
ros2 topic echo /roborescue/blue_box_pose

# Caja amarilla
ros2 topic echo /roborescue/yellow_box_pose
```

### Ver Imagen con ArUcos Detectados (Debug)

```bash
# En terminal con ROS sourced:
ros2 run image_view image_view image:=/roborescue/zenital/image_raw

# O si tienes debug image:
ros2 run image_view image_view image:=/roborescue/field_debug
```

---

## 🐛 Troubleshooting

Para problemas comunes, ver:
- **ArUcos no detectados:** `docs/troubleshooting/aruco-detection.md`
- **Posiciones incorrectas:** `docs/troubleshooting/aruco-detection.md` → sección "Homografía"
- **Cámara no conecta:** `docs/guias/GUIA_ROBOT_LOCALIZATION.md` → sección "Troubleshooting"

---

## 📚 Documentación Relacionada

- **Guía de Uso Completa:** `docs/guias/GUIA_ROBOT_LOCALIZATION.md`
- **Troubleshooting ArUco:** `docs/troubleshooting/aruco-detection.md`
- **Arquitectura del Sistema:** `docs/architecture/ARQUITECTURA_SISTEMA.md`
- **OpenCV ArUco Oficial:** https://docs.opencv.org/4.x/d5/dae/tutorial_aruco_detection.html

---

## 🔗 Código Principal

- `camera_publisher.py` — Lee cámara IP y publica frames
- `field_localizer.py` — Detecta ArUcos y calcula homografía (PRINCIPAL)
- `aruco_navigator.py` — Placeholder para navegación (futuro)

---

## 📦 Instalación Rápida

```bash
# 1. Compilar
colcon build --packages-select robot_localization

# 2. Fuente
source install/setup.bash

# 3. Editar configuración si es necesario
nano src/robot_localization/config/robot_localization.yaml

# 4. Lanzar
ros2 launch robot_localization robot_localization.launch.py
```

---

## 📝 Notas de Desarrollo

- **Diccionario ArUco:** Usa DICT_6X6_250 (IDs 0-249)
- **Frecuencia:** 10 Hz (cámara y detección)
- **Latencia:** ~100-150 ms (captura + procesamiento)
- **Precisión:** ±2-3 cm típicamente (depende de calibración de cámara)

---

**Última actualización:** 2026-03-05  
**Mantenedor:** Team RoboRescue

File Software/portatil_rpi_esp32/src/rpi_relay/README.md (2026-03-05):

# rpi_relay Package

## 📋 Descripción

El paquete **rpi_relay** implementa un **nodo relay simple** que reenvía mensajes de control (`Twist`) desde la **laptop** hacia el **ESP32** a través de la **Raspberry Pi 4**.

**Función:** Puente de comunicación ROS2 que conecta:
- Entrada: `/roborescue/cmd_vel_laptop` (desde laptop vía WiFi)
- Salida: `/roborescue/cmd_vel` (hacia ESP32 vía micro-ROS)

---

## 🏗️ Estructura del Paquete

```
rpi_relay/
├── rpi_relay/                    # Código fuente
│   ├── __init__.py
│   └── cmd_vel_relay.py          # Nodo principal
├── package.xml                   # Metadata del paquete
├── setup.py                      # Configuración Python
├── setup.cfg
└── README.md                     # Este archivo
```

---

## 🚀 Compilación

```bash
# En la raíz del workspace
cd ~/Desktop/GitHub/pruebas_eurobot

# Compilar
colcon build --packages-select rpi_relay

# Fuente
source install/setup.bash
```

---

## 🎯 Nodo Principal: cmd_vel_relay

**Ubicación:** `rpi_relay/cmd_vel_relay.py`

**Propósito:** Reenviar mensajes Twist desde una entrada a una salida con namespace configurable

### Tópicos

| Tópico | Tipo | Dirección | Descripción |
|---|---|---|---|
| `/{namespace}/cmd_vel_laptop` | `geometry_msgs/Twist` | Suscriptor | Comandos desde laptop |
| `/{namespace}/cmd_vel` | `geometry_msgs/Twist` | Publicador | Comandos hacia ESP32 |

### Parámetros

| Parámetro | Tipo | Valor Por Defecto | Descripción |
|---|---|---|---|
| `namespace` | string | `roborescue` | Namespace para los tópicos |

---

## ▶️ Ejecución

### Modo Simple

```bash
# En RPI, ejecutar:
ros2 run rpi_relay cmd_vel_relay

# Salida esperada:
# ✅ Nodo relay iniciado. Reenviando /roborescue/cmd_vel_laptop → /roborescue/cmd_vel
```

### Con Namespace Personalizado

```bash
ros2 run rpi_relay cmd_vel_relay \
    --ros-args \
    -p namespace:=robot_secondary
```

---

## 🧪 Verificación

```bash
# Ver que el nodo corre
ros2 node list
# Debería mostrar: /cmd_vel_relay

# Ver topics
ros2 topic list | grep cmd_vel
# Debería mostrar: /roborescue/cmd_vel_laptop
# Debería mostrar: /roborescue/cmd_vel

# Monitorear entrada
ros2 topic echo /roborescue/cmd_vel_laptop

# Monitorear salida
ros2 topic echo /roborescue/cmd_vel

# Enviar comando de prueba
ros2 topic pub --once /roborescue/cmd_vel_laptop geometry_msgs/msg/Twist \
    "{linear: {x: 0.5, y: 0.0, z: 0.0}, angular: {x: 0.0, y: 0.0, z: 0.0}}"
```

---

## 📊 Topología ROS

```
Laptop (Controller)
    ↓ /roborescue/cmd_vel_laptop
RPI (rpi_relay)
    ↓ /roborescue/cmd_vel
ESP32 (micro-ROS)
    ↓
Motores
```

---

## 🔧 Cómo Funciona

El nodo:
1. **Se suscribe** a `/{namespace}/cmd_vel_laptop`
2. **Recibe** cada mensaje Twist
3. **Lo reenvía sin cambios** a `/{namespace}/cmd_vel`
4. **Logs debug** muestran los valores reenviados (opcional)

**Sin procesamiento adicional** - es un simple pass-through para permitir que la laptop y el ESP32 se comuniquen a través de la RPI.

---

## 🔗 Referencias

- **Guía Completa:** `docs/guias/GUIA_RPI_RELAY.md`
- **Código:** `src/rpi_relay/rpi_relay/cmd_vel_relay.py`
- **Arquitectura:** `docs/architecture/ARQUITECTURA_SISTEMA.md`

---

## 📋 Requisitos

- ROS2 Humble
- Python 3.10+
- Paquete `geometry_msgs`

---

## 📝 Notas

- Este paquete es **muy simple y confiable** - solo reenvía
- **Estateless** - sin memoria de estado
- **Bajo overhead** - mínima latencia
- **Debugging fácil** - monitorea entrada/salida con `ros2 topic echo`

---

**Última actualización:** 2026-03-05  
**Equipo:** RoboRescue

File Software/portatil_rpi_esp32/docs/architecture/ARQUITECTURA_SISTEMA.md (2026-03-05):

# Arquitectura del Sistema - Robot Eurobot 2026

## Visión General

El sistema está diseñado con una **arquitectura distribuida** de tres niveles que separa las responsabilidades por capacidad computacional y función:

1. **Portátil** - Procesamiento de visión (localización + navegación)
2. **Raspberry Pi 4** - Relay de comandos y comunicación
3. **ESP32** - Control de bajo nivel y actuadores

### Sistema Actual: Localización Absoluta con Homografía

El sistema implementa **localización absoluta en el campo** mediante:
- 4 ArUcos fijos en las esquinas del campo como referencia (IDs 20-23)
- Cálculo de homografía píxeles ↔ coordenadas reales del campo
- Transformación de posiciones/orientaciones a sistema global (X, Y en cm)

---

## Diagrama de Arquitectura General

```
╔════════════════════════════════════════════════════════════════════╗
║              ARQUITECTURA DEL SISTEMA (CON HOMOGRAFÍA)             ║
╚════════════════════════════════════════════════════════════════════╝

┌──────────────────────────────────────────────────────────────────────┐
│                      NIVEL DE PERCEPCIÓN                             │
│                        (PORTÁTIL)                                    │
├──────────────────────────────────────────────────────────────────────┤
│                                                                      │
│  ┌─────────────┐     ┌──────────────────┐     ┌─────────────────┐  │
│  │  Cámara IP  │────►│  Nodo OpenCV     │────►│ Nodo Localiza   │  │
│  │  (Ethernet/ │     │  - Captura       │     │ ArUco           │  │
│  │   WiFi)     │     │  - Preproceso    │     │ - Homografía    │  │
│  └─────────────┘     └──────────────────┘     │ - Poses ABS     │  │
│                                │                └─────────────────┘  │
│                                ▼                        │            │
│                      /zenital/image_raw     /robot_pose (ABS)       │
│                                             /blue_box_pose (ABS)    │
│                                             /yellow_box_pose (ABS)  │
│                                                                      │
│  CLAVE: Coordenadas ABSOLUTAS del campo (cm)                        │
│  - Origen: esquina sup-izq (ArUco 20)                               │
│  - 4 ArUcos fijos (20,21,22,23) en esquinas                         │
│  - Homografía recalculada cada 30 frames si están visibles          │
└────────────────────────────────┬───────────────────┬────────────────┘
                                 │     ROS2 WiFi     │
                                 │    DDS Network    │
┌────────────────────────────────┴───────────────────┴────────────────┐
│              NIVEL DE DECISIÓN Y CONTROL                            │
│                   (RASPBERRY PI 4)                                  │
├──────────────────────────────────────────────────────────────────────┤
│                                                                      │
│  ┌───────────────────────────────────────────────────────────────┐  │
│  │        micro-ROS Agent                                        │  │
│  │  - Puente ROS2 ↔ micro-ROS                                  │  │
│  │  - Serial/WiFi con ESP32                                    │  │
│  │  - Relayea /cmd_vel_laptop → /cmd_vel                       │  │
│  └────────────────────────┬────────────────────────────────────┘  │
│                           │                                        │
│                           ▼                                        │
│                    /cmd_vel (Twist)                                │
└─────────────────────────────┼────────────────────────────────────────┘
                              │   Serial/WiFi
                              │   micro-ROS
┌─────────────────────────────┴───────────────────────────────────────┐
│                    NIVEL DE ACTUACIÓN                               │
│                        (ESP32)                                      │
├──────────────────────────────────────────────────────────────────────┤
│                                                                      │
│  ┌────────────────┐    ┌────────────────────┐   ┌───────────────┐  │
│  │ Nodo micro-ROS │───►│ Cinemática Inversa │──►│ Control PWM   │  │
│  │ - Sub /cmd_vel │    │ Mecanum (X-Drive)  │   │ - 4 motores   │  │
│  │ - Watchdog     │    │ - Cálculo ruedas   │   │ - 2 drivers H │  │
│  └────────────────┘    └────────────────────┘   └───────┬───────┘  │
│                                                           │          │
│                                                           ▼          │
│                                          ┌──────────────────────┐   │
│                                          │   Hardware Físico    │   │
│                                          │ - 4 Motores Mecanum  │   │
│                                          │ - 2 Puentes H        │   │
│                                          │ - Encoders           │   │
│                                          └──────────────────────┘   │
└──────────────────────────────────────────────────────────────────────┘
```

---

## Flujo de Datos Detallado

### 1. Percepción → Decisión

```
[Cámara IP]
    │
    ▼ (stream RTSP/HTTP)
[Portátil: Nodo captura]
    │
    ▼ (OpenCV processing)
[Portátil: Detector ArUco/Objetos]
    │
    ▼ (ROS2 topic: /detections)
[RPI4: Fusión sensorial]
    │
    ├─► Posición robot (x, y, θ)
    ├─► Objetos detectados
    └─► Mapa de obstáculos
```

### 2. Decisión → Control

```
[RPI4: Fusión Sensorial]
    │
    ▼ (Estado actual del robot)
[RPI4: Planificador]
    │
    ├─► Estrategia de juego
    ├─► Path Planning (A*, DWA, etc.)
    └─► Waypoints objetivo
    │
    ▼
[RPI4: Controlador de navegación]
    │
    ├─► Control PID
    ├─► Cálculo velocidades (vx, vy, wz)
    └─► Publicar /cmd_vel
```

### 3. Control → Actuación

```
[RPI4: Topic /cmd_vel]
    │
    ▼ (micro-ROS bridge)
[RPI4: micro-ROS Agent]
    │
    ▼ (Serial/WiFi)
[ESP32: micro-ROS Client]
    │
    ▼ (Callback subscription)
[ESP32: Cinemática Mecanum]
    │
    ├─► Calcular velocidad FL
    ├─► Calcular velocidad FR
    ├─► Calcular velocidad RL
    └─► Calcular velocidad RR
    │
    ▼
[ESP32: Control PWM]
    │
    ├─► Motor FL (PWM + DIR)
    ├─► Motor FR (PWM + DIR)
    ├─► Motor RL (PWM + DIR)
    └─► Motor RR (PWM + DIR)
    │
    ▼
[Motores físicos] → Robot se mueve
```

---

## Componentes de Software

### Portátil (Ubuntu 22.04 + ROS2 Humble)

#### Paquete: `robot_localization` (NUEVO)

**Nodos:**
- `camera_publisher` - Captura de stream de cámara IP
- `field_localizer` - Detección de ArUcos + Homografía → Poses absolutas
- `aruco_navigator` (futuro) - Navegación hacia objetivos en coordenadas del campo

**Topics publicados:**
- `/roborescue/zenital/image_raw` (sensor_msgs/Image)
- `/roborescue/zenital/image_raw/compressed` (CompressedImage) - **Recomendado para WiFi**
- `/roborescue/zenital/debug` (sensor_msgs/Image) - Con anotaciones ArUco
- `/roborescue/robot_pose` (geometry_msgs/Pose2D) - **Posición ABSOLUTA en cm + theta en grados**
- `/roborescue/blue_box_pose` (geometry_msgs/Pose2D) - **Posición ABSOLUTA**
- `/roborescue/yellow_box_pose` (geometry_msgs/Pose2D) - **Posición ABSOLUTA**

**Parámetros:**
- `robot_id` - ID del ArUco del robot (default: 1)
- `blue_box_id` - ID de caja azul (default: 36)
- `yellow_box_id` - ID de caja amarilla (default: 47)
- `fixed_ids` - IDs de los 4 ArUcos fijos (default: [20, 21, 22, 23])
- `field_width_cm` - Ancho del campo (default: 300)
- `field_height_cm` - Alto del campo (default: 200)
- `homography_update_every_n_frames` - Frecuencia de recalculación (default: 30)

**Dependencias:**
- OpenCV (cv2) - Para detección de ArUcos y transformaciones perspectivas
- cv_bridge
- NumPy

---

#### Paquete: `laptop_vision` (ANTERIOR - Referencia)

**Nodos:** (Sistema antiguo de visión relativa)
- `camera_publisher` - Captura de cámara IP
- `aruco_detector` - Detección con posiciones RELATIVAS al robot
- `aruco_navigator` - Navegación basada en visión relativa

**Topics publicados:**
- `/roborescue/robot_pose` (Pose2D) - Siempre (0, 0, 0) - referencia del robot
- `/roborescue/blue_box_pose` (Pose2D) - Posición RELATIVA a robot
- `/roborescue/yellow_box_pose` (Pose2D) - Posición RELATIVA a robot

---

### Raspberry Pi 4 (Ubuntu 22.04 + ROS2 Humble)

#### Paquete: `rpi_relay`

**Nodos:**
- `cmd_vel_relay` - Relay de comandos (reenvía `/cmd_vel_laptop` → `/cmd_vel`)

**Topics:**
- Suscribe: `/roborescue/cmd_vel_laptop` (Twist)
- Publica: `/roborescue/cmd_vel` (Twist) - Para ESP32 vía micro-ROS

#### Paquete: `micro_ros_agent`

**Función:** Puente de comunicación ROS2 ↔ micro-ROS

**Comando:**
```bash
ros2 run micro_ros_agent micro_ros_agent serial --dev /dev/ttyUSB0 -b 115200
```

---

### ESP32 (PlatformIO + micro-ROS)

#### Proyecto: `microros_esp_eurobot`

**Archivo principal:** `src/main.cpp`

**Funcionalidades:**
- Cliente micro-ROS
- Suscripción a `/cmd_vel`
- Cinemática inversa Mecanum
- Control PWM de 4 motores
- Watchdog de seguridad (timeout 500ms)

**Configuración Hardware:**
- **Transporte:** Serial (115200 baud) o WiFi
- **Pines PWM:** GPIO 25, 27, 18, 32
- **Pines DIR:** GPIO 26, 14, 19, 33
- **Canales PWM:** 4 (1 por motor)

**Dependencias (platformio.ini):**
- `micro_ros_platformio`
- Arduino framework

---

## Protocolos de Comunicación

### ROS2 DDS (Portátil ↔ Raspberry Pi)

**Transporte:** WiFi  
**Middleware:** DDS (Fast-RTPS por defecto)  
**Discovery:** Automático en la misma red

**Configuración de red:**
```bash
# Asegurar que ambos dispositivos están en la misma red WiFi
# Opcional: Configurar ROS_DOMAIN_ID para aislar
export ROS_DOMAIN_ID=42
```

**QoS Profiles:**
- Sensores (cámara): `BEST_EFFORT`, `VOLATILE`
- Control (cmd_vel): `RELIABLE`, `VOLATILE`

---

### micro-ROS (Raspberry Pi ↔ ESP32)

**Opción 1: Serial (Recomendado)**

```
RPI4 USB ───(Serial 115200)───► ESP32 UART0
```

**Ventajas:**
- Conexión estable
- Latencia baja y predecible
- No depende de WiFi

**Configuración RPI4:**
```bash
ros2 run micro_ros_agent micro_ros_agent serial --dev /dev/ttyUSB0 -b 115200
```

**Configuración ESP32:**
```cpp
Serial.begin(115200);
set_microros_serial_transports(Serial);
```

---

**Opción 2: WiFi (Alternativa)**

```
RPI4 WiFi ───(UDP)───► ESP32 WiFi
```

**Ventajas:**
- Sin cables
- Más flexible para debugging

**Desventajas:**
- Mayor latencia
- Puede tener pérdidas de paquetes

---

## Estrategia de Control

### Control de Velocidad (Twist)

**Mensaje:** `geometry_msgs/Twist`

```
linear:
  x: velocidad adelante/atrás (m/s)
  y: velocidad lateral (m/s)
  z: 0 (no usado)
angular:
  x: 0 (no usado)
  y: 0 (no usado)
  z: velocidad angular (rad/s)
```

### Cinemática Mecanum (X-Drive)

**Ecuaciones:**
```
vFL = vx - vy - wz
vFR = vx + vy + wz
vRL = vx + vy - wz
vRR = vx - vy + wz
```

**Normalización:**
Si `max(|vFL|, |vFR|, |vRL|, |vRR|) > 1.0`, dividir todas por el máximo.

### Control de Posición

**Algoritmo:** Control basado en visión (Visual Servoing)

1. Detectar posición del robot (ArUco ID=1)
2. Calcular error en coordenadas globales: `error = target - current`
3. Transformar a coordenadas del robot (rotación por -θ)
4. Aplicar control proporcional: `v = Kp * error`
5. Publicar en `/cmd_vel`

**Parámetros:**
- `KP_LIN = 1.5` (ganancia lineal)
- `DISTANCE_STOP = 0.15m` (distancia de parada)

---

## Seguridad y Robustez

### Watchdog en ESP32

**Timeout:** 500ms sin recibir `/cmd_vel` → Parar todos los motores

```cpp
if (millis() - last_msg_time > 500) {
  // Detener todos los motores
  set_motor(ch_FL, FL_DIR, 0);
  set_motor(ch_FR, FR_DIR, 0);
  set_motor(ch_RL, RL_DIR, 0);
  set_motor(ch_RR, RR_DIR, 0);
}
```

### Zona Muerta de Motores

**Threshold:** PWM < 25 → PWM = 0

Evita enviar señales insuficientes que podrían dañar los motores.

### Límites de Velocidad

**Máxima velocidad normalizada:** 1.0 (100% PWM)  
**En m/s:** Depende de calibración (a medir)

---

## Escalabilidad y Extensiones Futuras

### Sensores Adicionales

- **LIDAR 2D:** Para detección de obstáculos robusta
- **IMU:** Para mejorar odometría
- **Sensores de distancia:** Ultrasonido/IR para colisiones

**Integración:** Nuevos nodos ROS2 que publican en topics estándar

### Actuadores Adicionales

- **Servomotores:** Para manipulación de objetos
- **Sistemas neumáticos:** Si el reglamento lo permite

**Integración:** Extender control en ESP32 o añadir Arduino secundario

### SIMA (Small Independent Mobile Actuator)

**Descripción:** Robot pequeño secundario (Ø100mm)

**Arquitectura:**
- ESP32 independiente con micro-ROS
- Comunicación WiFi con RPI4
- Estrategia coordinada con robot principal

---

## Herramientas de Debug

### Visualización

**RViz2:**
```bash
ros2 run rviz2 rviz2
```

**rqt_image_view:**
```bash
ros2 run rqt_image_view rqt_image_view
```

### Monitoreo de Topics

```bash
# Ver todos los topics
ros2 topic list

# Monitorear cmd_vel
ros2 topic echo /cmd_vel

# Medir frecuencia
ros2 topic hz /cmd_vel
```

### Logs

```bash
# Ver logs de un nodo
ros2 node info /navigation_controller

# Grabar topics para análisis
ros2 bag record -a  # Grabar todos
ros2 bag play <bag_file>  # Reproducir
```

---

## Diagrama de Estados (Partido)

```
    ┌─────────┐
    │  INIT   │
    └────┬────┘
         │
         ▼
    ┌─────────┐
    │  READY  │◄──────────┐
    └────┬────┘           │
         │                │
         ▼ (señal inicio) │
    ┌─────────┐           │
    │ RUNNING │           │
    └────┬────┘           │
         │                │
         ├─► NAVIGATE ───►│
         ├─► COLLECT  ───►│
         ├─► SCORE    ───►│
         └─► AVOID    ───►│
         │                │
         ▼ (timeout/end)  │
    ┌─────────┐           │
    │  STOP   │           │
    └────┬────┘           │
         │                │
         ▼ (emergency)    │
    ┌─────────┐           │
    │  E-STOP │───────────┘
    └─────────┘
```

---

## Referencias Técnicas

- [ROS2 Humble Docs](https://docs.ros.org/en/humble/)
- [micro-ROS Docs](https://micro.ros.org/)
- [OpenCV Python](https://docs.opencv.org/4.x/)
- [ArUco Markers](https://docs.opencv.org/4.x/d5/dae/tutorial_aruco_detection.html)

---

**Versión:** 1.0  
**Fecha:** Febrero 2026  
**Autor:** Equipo Eurobot 2026

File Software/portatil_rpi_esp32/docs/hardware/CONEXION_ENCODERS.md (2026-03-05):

# Conexión de Encoders - ESP32 RoboRescue

## Especificaciones de los Encoders

- **PPR motor:** 11 pulsos por revolución
- **Relación de reducción:** 1:34
- **PPR eje rueda:** 374 pulsos/vuelta (11 × 34)
- **Resolución con cuadratura (x4):** 1496 counts/vuelta
- **Tipo:** Encoders incrementales de doble canal (A y B)

## Pines de cada Motor

Cada motor tiene 6 cables:
- Motor + (conectado al puente H)
- Motor - (conectado al puente H)
- Encoder GND
- Encoder +  (3.3V o 5V)
- Encoder A (fase A)
- Encoder B (fase B)

## Conexiones ESP32

### Alimentación de Encoders
Todos los encoders comparten:
- **Encoder GND** → GND del ESP32
- **Encoder +** → 3.3V del ESP32 (⚠️ Verificar si los encoders soportan 3.3V, si no usar 5V)

### Canales A y B por Motor

⚠️ **IMPORTANTE:** Se evitan GPIO 12 y 15 porque son sensibles durante el boot del ESP32 y causan problemas de programación cuando el robot está conectado.

| Motor | Posición | Canal A | Canal B |
|---|---|---|---|
| FL | Frontal Izquierda | GPIO 34 | GPIO 35 |
| FR | Frontal Derecha | GPIO 21 | GPIO 22 |
| RL | Trasera Izquierda | GPIO 23 | GPIO 4  |
| RR | Trasera Derecha | GPIO 16 | GPIO 17 |

### Esquema de Conexión

```
MOTOR FL (Frontal Izquierda):
  Motor + ────→ Puente H Driver 2 (ya conectado)
  Motor - ────→ Puente H Driver 2 (ya conectado)
  Encoder GND ─→ GND ESP32
  Encoder +  ──→ 3.3V ESP32
  Encoder A ───→ GPIO 34
  Encoder B ───→ GPIO 35

MOTOR FR (Frontal Derecha):
  Motor + ────→ Puente H Driver 2 (ya conectado)
  Motor - ────→ Puente H Driver 2 (ya conectado)
  Encoder GND ─→ GND ESP32
  Encoder +  ──→ 3.3V ESP32
  Encoder A ───→ GPIO 21
  Encoder B ───→ GPIO 22

MOTOR RL (Trasera Izquierda):
  Motor + ────→ Puente H Driver 1 (ya conectado)
  Motor - ────→ Puente H Driver 1 (ya conectado)
  Encoder GND ─→ GND ESP32
  Encoder +  ──→ 3.3V ESP32
  Encoder A ───→ GPIO 23
  Encoder B ───→ GPIO 4

MOTOR RR (Trasera Derecha):
  Motor + ────→ Puente H Driver 1 (ya conectado)
  Motor - ────→ Puente H Driver 1 (ya conectado)
  Encoder GND ─→ GND ESP32
  Encoder +  ──→ 3.3V ESP32
  Encoder A ───→ GPIO 16
  Encoder B ───→ GPIO 17
```

## Configuración en el Código

El archivo `esp32_roborescue/src/main.cpp` incluye:

1. **Definición de pines** (líneas 32-45)
2. **Interrupciones ISR** para lectura en cuadratura
3. **Cálculo de velocidad** cada 50ms
4. **Publicación ROS** en `/roborescue/encoder_velocities`

### Mensaje ROS Publicado

**Topic:** `/roborescue/encoder_velocities`  
**Tipo:** `std_msgs/Float32MultiArray`  
**Contenido:** `[rpm_FL, rpm_FR, rpm_RL, rpm_RR]`

Velocidades de las 4 ruedas en RPM (revoluciones por minuto).

## Guía de Pruebas

### 1. Compilar y Subir el Código

```bash
cd ~/Desktop/GitHub/pruebas_eurobot/esp32_roborescue
pio run --target upload
```

### 2. Verificar Monitor Serial

```bash
pio device monitor
```

**Salida esperada:**
```
========================================
   INICIANDO ESP32 MECANUM
========================================
✅ Hardware configurado
Configurando encoders...
✅ Encoders configurados
...
Encoders RPM -> FL:0.00 FR:0.00 RL:0.00 RR:0.00
```

### 3. Verificar Topic ROS

```bash
export ROS_DOMAIN_ID=17
ros2 topic echo /roborescue/encoder_velocities
```

**Salida esperada (robot detenido):**
```yaml
data:
- 0.0  # FL
- 0.0  # FR
- 0.0  # RL
- 0.0  # RR
```

### 4. Probar Durante Movimiento

**Configurar sistema:**

```bash
# Terminal 1 (RPI): micro-ROS agent
export ROS_DOMAIN_ID=17
ros2 run micro_ros_agent micro_ros_agent serial --dev /dev/ttyUSB0 -b 115200

# Terminal 2 (RPI): Relay
export ROS_DOMAIN_ID=17
ros2 run rpi_relay cmd_vel_relay

# Terminal 3: Monitorear encoders
export ROS_DOMAIN_ID=17
ros2 topic echo /roborescue/encoder_velocities
```

**Enviar comandos de prueba:**

```bash
export ROS_DOMAIN_ID=17

# Avance frontal
ros2 topic pub --once /roborescue/cmd_vel geometry_msgs/Twist \
  "{linear: {x: 0.2, y: 0.0, z: 0.0}, angular: {x: 0.0, y: 0.0, z: 0.0}}"

# Movimiento lateral
ros2 topic pub --once /roborescue/cmd_vel geometry_msgs/Twist \
  "{linear: {x: 0.0, y: 0.2, z: 0.0}, angular: {x: 0.0, y: 0.0, z: 0.0}}"

# Rotación
ros2 topic pub --once /roborescue/cmd_vel geometry_msgs/Twist \
  "{linear: {x: 0.0, y: 0.0, z: 0.0}, angular: {x: 0.0, y: 0.0, z: 0.5}}"

# Detener
ros2 topic pub --once /roborescue/cmd_vel geometry_msgs/Twist \
  "{linear: {x: 0.0, y: 0.0, z: 0.0}, angular: {x: 0.0, y: 0.0, z: 0.0}}"
```

### Valores Esperados

**Avance frontal (linear.x = 0.2):**
- Las 4 ruedas con valores similares (~30-60 RPM)

**Lateral (linear.y = 0.2):**
- FL y RR: mismo signo
- FR y RL: signo opuesto

**Rotación (angular.z = 0.5):**
- FL y RL: mismo signo
- FR y RR: signo opuesto

### Interpretación de RPM

**Cálculo:**
```
RPM = (counts_en_50ms × 1000 / 50) × 60 / 1496
```

**Rangos típicos:**
- Robot detenido: 0.0 RPM
- Velocidad baja (0.1 m/s): 15-30 RPM
- Velocidad media (0.2 m/s): 30-60 RPM
- Velocidad alta (0.3 m/s): 60-90 RPM

## Notas Técnicas

### Voltaje de Encoders
- **3.3V:** Opción más segura, menor consumo
- **5V:** Usar si encoders requieren 5V (verificar datasheet)

### GPIO Sensibles Durante Boot
- **GPIO 12 y 15:** Evitados por causar problemas de flash
- **Solución:** Usar GPIO 21, 22, 23 en su lugar

### Dirección de Rotación
Si un encoder cuenta en dirección inversa:
- Intercambiar físicamente cables A y B de ese encoder

### Interferencias
Para reducir ruido electromagnético:
- Añadir condensadores 100nF entre A/B y GND
- Separar cables de encoders de cables de potencia
- Usar cable apantallado si es posible

---

**Troubleshooting:** Ver `docs/TROUBLESHOOTING.md` para solución de problemas comunes.

**Última actualización:** Febrero 2026

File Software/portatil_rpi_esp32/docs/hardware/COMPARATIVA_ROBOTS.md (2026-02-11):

# Comparativa de Robots - RoboRescue vs Casa

Este documento explica las diferencias entre los dos robots del proyecto.

---

## Vista General

| Característica | Robot RoboRescue (Universidad) | Robot Casa (Pruebas) |
|---|---|---|
| **Propósito** | Competición Eurobot 2026 | Desarrollo y pruebas personales |
| **Ubicación código** | `esp32_roborescue/` | `esp32_casa/` |
| **Estado** | ✅ Operativo | ⚠️ En desarrollo |
| **Ruedas** | ✅ 4x Mecanum instaladas | ⏳ Pendiente de recibir |
| **Drivers** | 2x DFRobot | 2x L298N |

---

## Diferencias de Hardware

### Drivers de Motores

#### RoboRescue - DFRobot
```
Control simple: PWM + DIR por motor
- PWM (0-255): Controla velocidad
- DIR (HIGH/LOW): Controla dirección
  - HIGH = Adelante
  - LOW = Atrás

Conexiones por motor: 2 pines
Total pines usados: 8 (4 motores × 2)
```

#### Casa - L298N
```
Control clásico: 2×IN + EN por motor
- IN1/IN2: Controla dirección mediante tabla de verdad
  - IN1=HIGH, IN2=LOW = Adelante
  - IN1=LOW, IN2=HIGH = Atrás
  - IN1=LOW, IN2=LOW = Freno
- EN (PWM 0-255): Controla velocidad

Conexiones por motor: 3 pines (2 por driver compartiendo EN)
Total pines usados: 12
```

---

## Tabla de Pines

### RoboRescue (DFRobot)

| Motor | Ubicación | PWM Pin | DIR Pin | Notas |
|---|---|---|---|---|
| FL | Frontal Izquierda | GPIO18 | GPIO19 | Driver 2 |
| FR | Frontal Derecha | GPIO32 | GPIO33 | Driver 2 |
| RL | Trasera Izquierda | GPIO25 | GPIO26 | Driver 1 |
| RR | Trasera Derecha | GPIO27 | GPIO14 | Driver 1 |

**Total: 8 pines GPIO**

### Casa (L298N)

| Motor | Ubicación | EN Pin | IN1 | IN2 | Notas |
|---|---|---|-----|-----|---|
| M2 | Frontal Izquierda | GPIO15 | GPIO2 | GPIO4 | Driver 2 |
| M3 | Frontal Derecha | GPIO5 | GPIO16 | GPIO17 | Driver 2 |
| M0 | Trasera Izquierda | GPIO32 | GPIO33 | GPIO25 | Driver 1 |
| M1 | Trasera Derecha | GPIO14 | GPIO26 | GPIO27 | Driver 1 |

**Total: 12 pines GPIO**

**⚠️ Nota:** GPIO16 y GPIO17 son RX2/TX2 - Verificar que no interfieran con Serial2

---

## Código - Función de Control de Motor

### RoboRescue (DFRobot)

```cpp
void set_motor(int channel, int dir_pin, float speed) {
  // Limitar velocidad
  if (speed > 1.0) speed = 1.0;
  if (speed < -1.0) speed = -1.0;

  int pwm = abs(speed) * 255;
  
  // Zona muerta
  if (pwm < 25) pwm = 0;

  // Control dirección (simple)
  if (speed > 0) {
    digitalWrite(dir_pin, HIGH);  // Adelante
  } else {
    digitalWrite(dir_pin, LOW);   // Atrás
  }
  
  // Aplicar velocidad
  ledcWrite(channel, pwm);
}
```

### Casa (L298N)

```cpp
void controlar_motor(int id, float speed) {
  // Convertir a PWM
  int pwm_value = abs(speed) * 255;
  if (pwm_value > 255) pwm_value = 255;
  
  // Zona muerta
  if (pwm_value < 20) {
    pwm_value = 0;
    speed = 0; 
  }

  int pin_in1, pin_in2, canal_pwm;
  // Asignar pines según ID...
  
  // Control dirección (tabla de verdad)
  if (speed > 0) {
    digitalWrite(pin_in1, HIGH);
    digitalWrite(pin_in2, LOW);   // Adelante
  } 
  else if (speed < 0) {
    digitalWrite(pin_in1, LOW);
    digitalWrite(pin_in2, HIGH);  // Atrás
  } 
  else {
    digitalWrite(pin_in1, LOW);
    digitalWrite(pin_in2, LOW);   // Freno
  }
  
  // Aplicar velocidad
  ledcWrite(canal_pwm, pwm_value);
}
```

---

## Cinemática (Igual en ambos)

Ambos robots usan la misma cinemática Mecanum X-Drive:

```cpp
// Entradas del topic /cmd_vel
float vx = msg->linear.x;   // Adelante/atrás
float vy = msg->linear.y;   // Lateral
float wz = msg->angular.z;  // Rotación

// Cálculo de velocidades por rueda
float vFL = vx - vy - wz;   // Frontal Izquierda
float vFR = vx + vy + wz;   // Frontal Derecha
float vRL = vx + vy - wz;   // Trasera Izquierda
float vRR = vx - vy + wz;   // Trasera Derecha

// Normalización si excede 1.0
float max_val = max(abs(vFL), max(abs(vFR), max(abs(vRL), abs(vRR))));
if (max_val > 1.0) {
  vFL /= max_val;
  vFR /= max_val;
  vRL /= max_val;
  vRR /= max_val;
}
```

---

## Comunicación micro-ROS (Igual en ambos)

Ambos usan el mismo protocolo:

```cpp
// Setup
Serial.begin(115200);
set_microros_serial_transports(Serial);

// Crear nodo
rclc_node_init_default(&node, "nombre_nodo", "", &support);

// Suscribirse a /cmd_vel
rclc_subscription_init_default(&subscriber, &node,
  ROSIDL_GET_MSG_TYPE_SUPPORT(geometry_msgs, msg, Twist),
  "cmd_vel");
```

**Diferencia:** Nombre del nodo
- RoboRescue: `"esp32_mecanum"`
- Casa: `"microros_esp32_omni"`

---

## Cuándo Usar Cada Uno

### Robot RoboRescue 🏆
**Usar para:**
- ✅ Competición oficial Eurobot 2026
- ✅ Pruebas finales antes de competir
- ✅ Calibración con hardware definitivo
- ✅ Entrenamiento del equipo

**NO usar para:**
- ❌ Experimentos arriesgados
- ❌ Desarrollo de features sin probar
- ❌ Pruebas que puedan dañar hardware

### Robot Casa 🏠
**Usar para:**
- ✅ Desarrollo de nuevas funcionalidades
- ✅ Pruebas de algoritmos de navegación
- ✅ Aprendizaje personal
- ✅ Experimentos con código
- ✅ Depuración antes de pasar a RoboRescue

**Ventaja:** Si algo falla, no afecta al robot de competición

---

## Migración de Código entre Robots

### De Casa → RoboRescue

1. ✅ La cinemática es idéntica (copiar directamente)
2. ✅ La lógica de control ROS es igual
3. ⚠️ Cambiar función de control de motor:
   - `controlar_motor()` (L298N) → `set_motor()` (DFRobot)
4. ⚠️ Actualizar asignación de pines
5. ⚠️ Cambiar nombre del nodo si es necesario

### De RoboRescue → Casa

Proceso inverso, cambiar control de motores y pines.

---

## Recomendaciones

### Workflow Sugerido

1. **Desarrollar en Casa:** Probar nuevas ideas en el robot de pruebas
2. **Verificar código:** Asegurar que funciona correctamente
3. **Migrar a RoboRescue:** Adaptar el código probado al robot de competición
4. **Probar en RoboRescue:** Validar con hardware final
5. **Competir:** Usar solo código estable y probado

### Backup y Seguridad

- Mantener siempre un código funcional de respaldo en RoboRescue
- Hacer commits frecuentes cuando el código funciona
- Documentar cambios importantes
- Probar primero en Casa siempre que sea posible

---

## Troubleshooting

### Problema: Motor gira al revés

**RoboRescue (DFRobot):**
```cpp
// Invertir lógica DIR
digitalWrite(dir_pin, speed > 0 ? LOW : HIGH);  // Invertido
```

**Casa (L298N):**
```cpp
// Intercambiar IN1 e IN2 en la asignación de pines
// O invertir en el código:
if (speed > 0) {
  digitalWrite(pin_in1, LOW);   // Invertido
  digitalWrite(pin_in2, HIGH);  // Invertido
}
```

### Problema: Motor no responde

- Verificar conexiones de pines
- Verificar alimentación del driver
- Comprobar que el canal PWM está bien configurado
- Revisar que la zona muerta no esté muy alta

### Problema: Movimiento lateral incorrecto

- Verificar orientación de ruedas Mecanum
- Comprobar que los motores están en las posiciones correctas (FL, FR, RL, RR)
- Revisar las ecuaciones de cinemática

---

**Última actualización:** Febrero 2026  
**Equipo:** RoboRescue

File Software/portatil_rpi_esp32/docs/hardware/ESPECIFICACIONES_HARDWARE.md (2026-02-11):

# Especificaciones Técnicas del Hardware - Robot Eurobot 2026

## Arquitectura General del Sistema

### Descripción
El robot utiliza una arquitectura **distribuida** basada en tres componentes principales que se comunican mediante ROS2:

```
┌─────────────────┐         ┌─────────────────┐         ┌─────────────────┐
│    PORTÁTIL     │◄───────►│   RASPBERRY PI 4│◄───────►│     ESP32       │
│                 │         │                 │         │                 │
│  Procesamiento  │  WiFi   │  Navegación y   │ Serial/ │   Control de    │
│  de Visión      │  ROS2   │  Coordinación   │ WiFi    │   Motores       │
│                 │         │                 │ microROS│                 │
└─────────────────┘         └─────────────────┘         └─────────────────┘
        │                           │                           │
        │                           │                           │
    Cámara IP                   Cámara zenital            4x Motores DC
                                   ArUco                 con Encoders
```

---

## Componentes Hardware

### 1. Portátil (Procesamiento de Visión)

**Función:** Procesamiento intensivo de imágenes de la cámara IP

**Tareas:**
- Captura y procesamiento de video en tiempo real
- Detección de elementos del juego
- Detección de marcadores ArUco
- Publicación de información procesada vía ROS2

**Conexión:**
- WiFi para ROS2 topics
- Comunicación con cámara IP

---

### 2. Raspberry Pi 4 (Cerebro del Robot)

**Función:** Coordinación, navegación y control de alto nivel

**Especificaciones:**
- Modelo: Raspberry Pi 4 (4GB RAM recomendado)
- OS: Ubuntu 22.04 / ROS2 Humble

**Tareas:**
- Ejecutar nodos de navegación y planificación
- Recibir datos procesados del portátil
- Enviar comandos de velocidad a ESP32
- Ejecutar micro-ROS agent
- Localización del robot (usando cámara zenital + ArUco)

**Conexión:**
- WiFi para ROS2 (comunicación con portátil)
- Serial/WiFi para micro-ROS (comunicación con ESP32)
- USB para cámara zenital (opcional)

---

### 3. ESP32 (Control de Bajo Nivel)

**Función:** Control directo de motores y actuadores

**Especificaciones:**
- Microcontrolador: ESP32-DevKit o similar
- Framework: PlatformIO + micro-ROS

**Tareas:**
- Recibir comandos Twist (`/cmd_vel`) vía micro-ROS
- Implementar cinemática inversa para ruedas Mecanum
- Control PWM de los 4 motores
- Lectura de encoders (futuro)

**Conexión:**
- Serial o WiFi con Raspberry Pi (micro-ROS)
- GPIO para drivers de motores

---

## Sistema de Locomoción

### Configuración: Ruedas Mecanum (X-Drive)

**Cantidad:** 4 ruedas omni-direccionales Mecanum

**Distribución:**
```
        FRENTE
    FL -------- FR
    |    ↑     |
    |    |     |
    RL -------- RR
       TRASERA
```

- **FL:** Front Left (Delantera Izquierda)
- **FR:** Front Right (Delantera Derecha)
- **RL:** Rear Left (Trasera Izquierda)
- **RR:** Rear Right (Trasera Derecha)

**Características:**
- Movimiento omnidireccional (X, Y, rotación)
- Rodamientos a 45° en las ruedas
- Permite movimiento lateral sin girar

### Cinemática Inversa (X-Drive)

```cpp
// Entradas: vx, vy, wz (velocidad lineal X, Y y angular Z)
fl = vx - vy - wz
fr = vx + vy + wz
rl = vx + vy - wz
rr = vx - vy + wz
```

---

## Motores y Drivers

### Motores DC con Encoders

**Cantidad:** 4 motores

**Especificaciones:**
- Tipo: Motores DC con reductora
- Encoders: Sí (para odometría y control preciso)
- Alimentación: Verificar voltaje (típicamente 6-12V)

### Drivers de Motores: 2x Puente H DFRobot

**Configuración:**
- **Driver 1 (Trasero):** Controla RL y RR
- **Driver 2 (Delantero):** Controla FL y FR

**Conexiones ESP32:**

| Motor | PWM Pin | DIR Pin | Canal PWM |
|---|---|---|---|
| RL | GPIO25  | GPIO26  | Canal 0 |
| RR | GPIO27  | GPIO14  | Canal 1 |
| FL | GPIO18  | GPIO19  | Canal 2 |
| FR | GPIO32  | GPIO33  | Canal 3 |

**Características DFRobot:**
- Control mediante PWM + DIR (dirección)
- DIR=HIGH → Adelante, DIR=LOW → Atrás
- PWM (0-255) controla la velocidad

---

## Sistema de Visión

### Cámara IP (Procesada por Portátil)

**Función:** Visión general del campo y detección de elementos

**Características:**
- Conexión: WiFi/Ethernet
- Resolución: HD (720p o superior recomendado)
- Ubicación: Montada en el robot o externa (verificar)

**Procesamiento:**
- OpenCV para detección de objetos
- Detección de ArUco markers
- Publicación en ROS2 topics

### Cámara Zenital + ArUco (Localización)

**Función:** Localización precisa del robot en el campo

**Configuración:**
- Cámara cenital sobre el campo
- Marcadores ArUco en el robot (ID específico, ej: ID=1)
- Diccionario ArUco: DICT_4X4_50

**Funcionamiento:**
- La cámara detecta el marcador del robot
- Calcula posición (X, Y) y orientación (Yaw)
- Permite navegación precisa

---

## Alimentación

### Consideraciones

**Reglamento Eurobot:**
- Tensión máxima: **48V DC**
- Baterías: LiPo con protección o similares

**Distribución (a confirmar):**
- Batería principal para motores
- Reguladores de voltaje para Raspberry Pi (5V)
- Regulador para ESP32 (5V o 3.3V)

**Seguridad:**
- Interruptor de emergencia accesible
- Protección contra cortocircuitos
- Indicador visual de estado (LED)

---

## Sensores y Actuadores Adicionales

### Actuales
- 4x Motores DC con encoders
- 2x Cámaras (IP + opcional zenital)
- Marcadores ArUco para localización

### Posibles Expansiones Futuras
- Sensores de distancia (ultrasonido, LIDAR)
- Servomotores para manipulación de objetos
- Sensores de color
- IMU (para odometría mejorada)
- SIMA (robot secundario pequeño)

---

## Dimensiones del Robot

**Reglamento Eurobot:**
- Diámetro inicial: **≤ 300mm**
- Altura máxima: **≤ 350mm**

**Dimensiones Reales:**
- A medir y documentar

**Peso:**
- A medir (sin límite reglamentario, pero considerar estabilidad)

---

## Comunicaciones

### Red ROS2

**Dominio ROS2:** Configurar DDS domain ID

**Topics principales:**
- `/camera_node/image_raw` - Imagen raw de cámara
- `/camera_node/aruco_image` - Imagen con ArUcos detectados
- `/zenital/image_raw` - Cámara zenital
- `/zenital/debug` - Debug de localización
- `/cmd_vel` (geometry_msgs/Twist) - Comandos de velocidad

**Nodos:**
- `aruco_detector` - Detección de ArUcos
- `eurobot_controller` - Control de navegación
- `esp32_mecanum` - Nodo micro-ROS en ESP32

### micro-ROS (Raspberry Pi ↔ ESP32)

**Transporte:** Serial (USB) o WiFi

**Configuración Raspberry Pi:**
```bash
ros2 run micro_ros_agent micro_ros_agent serial --dev /dev/ttyUSB0
```

**Configuración ESP32:**
```cpp
set_microros_serial_transports(Serial);
```

---

## Referencias de Código

### Ubicaciones

**Proyecto antiguo (referencia):**
- `/home/maki/Desktop/rpi_casa/src/`
  - `robot_vision/` - Detección ArUco
  - `robot_navigator/` - Control y navegación

**Proyecto ESP32 (micro-ROS):**
- `/home/maki/Documents/PlatformIO/Projects/microros_esp_eurobot/`
  - `src/main.cpp` - Control de motores Mecanum

**Proyecto actual:**
- `~/Desktop/laptop_rpi_esp/src/` - Paquetes ROS2 a migrar

---

## Estado del Proyecto

### Componentes Verificados
- ✅ ESP32 con micro-ROS (código base)
- ✅ Cinemática Mecanum implementada
- ✅ Proyecto ROS2 antiguo con visión funcional

### Componentes a Verificar
- ⚠️ Conexión micro-ROS ESP32 ↔ RPI4
- ⚠️ Drivers de motores y cableado
- ⚠️ Integración portátil-RPI4
- ⚠️ Calibración de cámaras
- ⚠️ Encoders de motores (lectura)

### Por Implementar
- ❌ Navegación autónoma completa
- ❌ Detección de elementos del juego 2026
- ❌ Estrategia de competición
- ❌ Tests de hardware completo

---

**Última actualización:** Febrero 2026  
**Responsable:** Equipo [Nombre del equipo]

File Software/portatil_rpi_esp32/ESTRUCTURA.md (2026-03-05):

# Estructura del Proyecto Eurobot 2026 - RoboRescue

```
laptop_rpi_esp/
│
├── README.md                           # 📘 Documentación principal
├── .gitignore                          # 🚫 Archivos ignorados por Git
│
├── docs/                               # 📚 DOCUMENTACIÓN
│   ├── reglamento/
│   │   ├── EurobotSenior_general.pdf   # Reglamento oficial completo
│   │   ├── Arena y puntuaciones.pdf    # Detalles del campo 2026
│   │   └── RESUMEN_REGLAMENTO.md       # ⭐ Resumen en español
│   ├── hardware/
│   │   ├── ESPECIFICACIONES_HARDWARE.md # ⭐ Hardware del robot
│   │   └── COMPARATIVA_ROBOTS.md        # ⭐ Diferencias RoboRescue vs Casa
│   └── architecture/
│       └── ARQUITECTURA_SISTEMA.md      # ⭐ Diagramas del sistema
│
├── src/                                # 🤖 PAQUETES ROS2
│   ├── robot_localization/             # 📍 Localización + Navegación (NUEVO)
│   │   ├── robot_localization/
│   │   │   ├── camera_publisher.py     # Captura cámara IP
│   │   │   ├── field_localizer.py      # Homografía + poses absolutas (NUEVO)
│   │   │   └── aruco_navigator.py      # Navegación (por implementar)
│   │   ├── launch/
│   │   │   └── robot_localization.launch.py
│   │   ├── config/
│   │   │   └── robot_localization.yaml
│   │   ├── package.xml
│   │   └── setup.py
│   ├── laptop_vision/                  # 👁️ Visión relativa (ANTIGUO)
│   │   ├── launch/
│   │   ├── config/
│   │   ├── package.xml
│   │   └── setup.py
│   ├── rpi_relay/                      # 🔗 Relay de comandos (RPI4)
│   │   ├── rpi_relay/
│   │   │   └── cmd_vel_relay.py
│   │   ├── package.xml
│   │   └── setup.py
│   ├── robot_vision/                   # (ANTIGUO - Backup)
│   │   └── ...
│   └── robot_navigator/                # (ANTIGUO - Backup)
│       └── ...
│
├── esp32_roborescue/                   # 🏆 ROBOT COMPETICIÓN (DFRobot)
│   ├── README.md                       # ⭐ Documentación específica
│   ├── platformio.ini                  # Configuración PlatformIO
│   ├── src/
│   │   └── main.cpp                    # Control Mecanum PWM+DIR
│   ├── include/
│   ├── lib/
│   └── test/
│
├── esp32_casa/                         # 🏠 ROBOT PRUEBAS (L298N)
│   ├── README.md                       # ⭐ Documentación específica
│   ├── platformio.ini                  # Configuración PlatformIO
│   ├── src/
│   │   └── main.cpp                    # Control Mecanum IN1/IN2+EN
│   ├── include/
│   ├── lib/
│   └── test/
│
├── config/                             # ⚙️ Configuraciones
├── launch/                             # 🚀 Launch files ROS2
│
├── build/                              # 🔨 Compilación ROS2 (ignorado)
├── install/                            # 📦 Instalación ROS2 (ignorado)
└── log/                                # 📝 Logs ROS2 (ignorado)
```

---

## Archivos Clave por Tarea

### 🎯 Para empezar
- `README.md` - Lee esto primero

### 📖 Entender el proyecto
- `docs/reglamento/RESUMEN_REGLAMENTO.md` - Reglas de la competición
- `docs/hardware/ESPECIFICACIONES_HARDWARE.md` - Hardware del robot
- `docs/architecture/ARQUITECTURA_SISTEMA.md` - Cómo funciona todo

### 📍 Nuevo Sistema de Localización (Actual)
- `docs/guias/GUIA_ROBOT_LOCALIZATION.md` - Guía de homografía y localización absoluta
- `src/robot_localization/` - Paquete de localización con poses absolutas
- `src/robot_localization/robot_localization/field_localizer.py` - Nodo principal

### 👁️ Sistema Anterior (Referencia)
- `docs/guias/GUIA_VISION_DISTRIBUIDA.md` - Guía del sistema de visión relativa
- `src/laptop_vision/` - Código anterior

### 🏆 Trabajar con robot de competición
- `esp32_roborescue/README.md` - Instrucciones específicas
- `esp32_roborescue/src/main.cpp` - Código ESP32 DFRobot

### 🏠 Trabajar con robot de pruebas
- `esp32_casa/README.md` - Instrucciones específicas
- `esp32_casa/src/main.cpp` - Código ESP32 L298N

### 🔍 Comparar robots
- `docs/hardware/COMPARATIVA_ROBOTS.md` - Diferencias detalladas

---

## Comandos Rápidos

### Compilar ROS2
```bash
cd ~/Desktop/laptop_rpi_esp
colcon build
source install/setup.bash
```

### Flashear Robot Competición
```bash
cd ~/Desktop/laptop_rpi_esp/esp32_roborescue
pio run --target upload
```

### Flashear Robot Casa
```bash
cd ~/Desktop/laptop_rpi_esp/esp32_casa
pio run --target upload
```

### Iniciar Git
```bash
cd ~/Desktop/laptop_rpi_esp
git init
git add .
git commit -m "Initial commit: Proyecto Eurobot 2026 - RoboRescue"
```

---

**Equipo:** RoboRescue  
**Competición:** Eurobot 2026 Senior  
**Última actualización:** Febrero 2026

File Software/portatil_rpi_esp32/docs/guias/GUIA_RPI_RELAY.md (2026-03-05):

# Guía de Uso - RPI Relay (cmd_vel_relay)

## 📋 Descripción General

**RPI Relay** es un nodo ROS2 que actúa como **puente de comunicación** entre los comandos de movimiento enviados desde la **laptop** y el **ESP32** (microcontrolador del robot) conectado a la **Raspberry Pi**.

**Ubicación del código:** `src/rpi_relay/`

---

## 🎯 Función Principal

El nodo reenvía (relay) mensajes `Twist` desde un tópico origen a un tópico de destino:

```
Laptop
    ↓ (publica a /roborescue/cmd_vel_laptop)
RPI Relay (suscriptor)
    ↓ (reenvía)
RPI Relay (publicador)
    ↓ (publica a /roborescue/cmd_vel)
ESP32 (micro-ROS)
    ↓
Motores
```

---

## 🏗️ Estructura

```
rpi_relay/
├── rpi_relay/
│   ├── __init__.py
│   └── cmd_vel_relay.py      # Nodo principal
├── launch/
│   └── rpi_relay.launch.py   # Launch file (si existe)
├── package.xml               # Metadata
├── setup.py                  # Configuración
└── README.md                 # Este archivo
```

---

## 🚀 Instalación y Compilación

### 1. Compilar el Paquete

```bash
# En la raíz del workspace
cd ~/Desktop/GitHub/pruebas_eurobot

# Compilar
colcon build --packages-select rpi_relay

# Fuente
source install/setup.bash
```

### 2. Verificar Compilación

```bash
# Verificar que el paquete es accesible
ros2 pkg list | grep rpi_relay

# Ver el nodo disponible
ros2 run rpi_relay --help
```

---

## 🎮 Uso Básico

### Opción 1: Sin Parámetros (Recomendado)

```bash
# En la RPI, ejecutar:
ros2 run rpi_relay cmd_vel_relay

# Salida esperada:
# ✅ Nodo relay iniciado. Reenviando /roborescue/cmd_vel_laptop → /roborescue/cmd_vel
```

### Opción 2: Con Parámetro de Namespace Personalizado

```bash
# Si quieres usar un namespace diferente (ej: /robot2/)
ros2 run rpi_relay cmd_vel_relay \
    --ros-args \
    -p namespace:=robot2

# Resultado: reenviará de /robot2/cmd_vel_laptop → /robot2/cmd_vel
```

### Opción 3: Con Launch File (Si Existe)

```bash
ros2 launch rpi_relay rpi_relay.launch.py
```

---

## 📊 Topología ROS

### Tópicos

| Tópico | Tipo | Dirección | Descripción |
|---|---|---|---|
| `/roborescue/cmd_vel_laptop` | `geometry_msgs/Twist` | Suscriptor | Comandos desde laptop |
| `/roborescue/cmd_vel` | `geometry_msgs/Twist` | Publicador | Comandos hacia ESP32 |

### Parámetros

| Parámetro | Tipo | Valor Por Defecto | Descripción |
|---|---|---|---|
| `namespace` | string | `roborescue` | Namespace para los tópicos |

---

## 🔧 Configuración

### Cambiar Namespace

Para usar un robot diferente o un namespace personalizado:

```bash
ros2 run rpi_relay cmd_vel_relay -p namespace:=roborescue_custom
```

Esto reenviará:
- De: `/roborescue_custom/cmd_vel_laptop`
- Hacia: `/roborescue_custom/cmd_vel`

---

## 🧪 Verificación de Funcionamiento

### Test 1: Verificar que el Nodo Corre

```bash
# En otra terminal:
ros2 node list

# Debería mostrar: /cmd_vel_relay
```

### Test 2: Monitorear Topics

```bash
# Terminal 1: Ver datos que llegan al relay
ros2 topic echo /roborescue/cmd_vel_laptop

# Terminal 2: Ver datos que salen del relay
ros2 topic echo /roborescue/cmd_vel

# Enviar un comando de prueba desde laptop:
ros2 topic pub --once /roborescue/cmd_vel_laptop geometry_msgs/msg/Twist \
    "{linear: {x: 0.5, y: 0.0, z: 0.0}, angular: {x: 0.0, y: 0.0, z: 0.0}}"

# Resultado esperado: El mismo mensaje debería aparecer en ambas terminales
```

### Test 3: Verificar Información del Topic

```bash
# Ver quién publica y suscribe
ros2 topic info /roborescue/cmd_vel_laptop
ros2 topic info /roborescue/cmd_vel

# Resultado esperado:
# /roborescue/cmd_vel_laptop:
#   Type: geometry_msgs/msg/Twist
#   Publishers: 1      (laptop)
#   Subscribers: 1     (relay)
#
# /roborescue/cmd_vel:
#   Type: geometry_msgs/msg/Twist
#   Publishers: 1      (relay)
#   Subscribers: 1     (ESP32 micro-ROS)
```

---

## 📐 Diagrama de Flujo

```
┌─────────────────────────────────────────────────┐
│            LAPTOP (Controlador)                 │
│                                                 │
│  - Xbox Teleop u otro nodo de control          │
│  - Publica a: /roborescue/cmd_vel_laptop       │
└──────────────┬──────────────────────────────────┘
               │
               │ ROS2 Network (WiFi/Ethernet)
               │ DDS - Domain ID 17
               ↓
┌──────────────────────────────────────────────────┐
│         RASPBERRY PI 4 (Relay)                   │
│                                                  │
│  ┌────────────────────────────────────────────┐ │
│  │   RPI Relay Node                           │ │
│  │                                            │ │
│  │   Suscriptor:                              │ │
│  │   └─ /roborescue/cmd_vel_laptop           │ │
│  │                                            │ │
│  │   Publicador:                              │ │
│  │   └─ /roborescue/cmd_vel                  │ │
│  └────────────────────────────────────────────┘ │
│                                                  │
│   (Ejecuta: ros2 run rpi_relay cmd_vel_relay)  │
└──────────────┬───────────────────────────────────┘
               │
               │ Serial o WiFi micro-ROS
               │
               ↓
┌──────────────────────────────────────────────────┐
│           ESP32 (microcontrolador)               │
│                                                  │
│   - Suscriptor: /roborescue/cmd_vel             │
│   - Cinemática inversa Mecanum                  │
│   - Control PWM de motores                      │
└──────────────────────────────────────────────────┘
```

---

## ⚙️ Integración en el Sistema

### Secuencia de Inicio Recomendada

```bash
# Terminal 1 (En RPI): Iniciar micro-ROS Agent
cd ~/Desktop/ros2_pi_esp
source install/setup.bash
ros2 run micro_ros_agent micro_ros_agent serial --dev /dev/ttyUSB0 -b 115200

# Terminal 2 (En RPI): Iniciar RPI Relay
cd ~/Desktop/GitHub/pruebas_eurobot
source install/setup.bash
export ROS_DOMAIN_ID=17
ros2 run rpi_relay cmd_vel_relay

# Terminal 3 (En Laptop): Iniciar sistema de visión y control
cd ~/Desktop/GitHub/pruebas_eurobot
source install/setup.bash
export ROS_DOMAIN_ID=17
ros2 launch robot_localization robot_localization.launch.py &
ros2 run xbox_controler xbox_teleop  # u otro controlador
```

---

## 🔍 Debugging y Troubleshooting

### Problema: El Relay No Recibe Comandos

**Verificación:**
```bash
# ¿Hay datos en /roborescue/cmd_vel_laptop?
ros2 topic echo /roborescue/cmd_vel_laptop

# Si no hay datos, revisar que el controlador (ej: Xbox Teleop) está publicando ahí
ros2 topic info /roborescue/cmd_vel_laptop
# Debería mostrar: Publishers: 1 (el controlador)
```

**Solución:**
- Verificar que el laptop tiene `ROS_DOMAIN_ID=17`
- Verificar que el controlador está corriendo en la laptop
- Ver logs del relay: `ros2 run rpi_relay cmd_vel_relay --ros-args --log-level DEBUG`

---

### Problema: El ESP32 No Recibe Comandos

**Verificación:**
```bash
# ¿Hay datos saliendo del relay?
ros2 topic echo /roborescue/cmd_vel

# Si no hay datos, el relay no está recibiendo
# Ver logs del relay
```

**Solución:**
- Verificar que el micro-ROS Agent está corriendo en RPI
- Verificar que ESP32 está conectado por USB: `ls /dev/ttyUSB*`
- Verificar que el ESP32 está suscrito: `ros2 node list | grep esp`

---

### Problema: Domain ID Mismatch

**Síntoma:** El relay no se conecta a la laptop o el ESP32

**Solución:**
```bash
# En RPI:
export ROS_DOMAIN_ID=17

# En laptop:
export ROS_DOMAIN_ID=17

# Verificar:
echo $ROS_DOMAIN_ID  # Debe ser 17 en ambas máquinas

# Persistente (.bashrc):
echo "export ROS_DOMAIN_ID=17" >> ~/.bashrc
source ~/.bashrc
```

---

## 📋 Comandos Útiles

```bash
# Ver nodos activos
ros2 node list

# Ver topics disponibles
ros2 topic list

# Ver información de un topic
ros2 topic info /roborescue/cmd_vel_laptop
ros2 topic info /roborescue/cmd_vel

# Monitorear datos en tiempo real
ros2 topic echo /roborescue/cmd_vel_laptop
ros2 topic echo /roborescue/cmd_vel

# Enviar comando de prueba
ros2 topic pub --once /roborescue/cmd_vel_laptop geometry_msgs/msg/Twist \
    "{linear: {x: 1.0, y: 0.0, z: 0.0}, angular: {x: 0.0, y: 0.0, z: 0.0}}"

# Matar el nodo
ros2 node kill /cmd_vel_relay

# Ver logs detallados
ros2 run rpi_relay cmd_vel_relay --ros-args --log-level DEBUG
```

---

## 📊 Formatos de Mensajes

### Twist (geometry_msgs/Twist)

Mensaje de control de velocidad:

```yaml
linear:
  x: float64  # Velocidad adelante/atrás (m/s típicamente, pero nosotros usamos normalizado -1.0 a 1.0)
  y: float64  # Velocidad lateral (Mecanum) (normalizado)
  z: float64  # Velocidad vertical (no usado en robots terrestres)
angular:
  x: float64  # Rotación en X (roll) - no usado
  y: float64  # Rotación en Y (pitch) - no usado
  z: float64  # Rotación en Z (yaw/giro) (normalizado -1.0 a 1.0)
```

**Ejemplo de movimiento:**
```bash
# Avanzar rápido
ros2 topic pub /roborescue/cmd_vel_laptop geometry_msgs/msg/Twist \
    "{linear: {x: 1.0, y: 0.0, z: 0.0}, angular: {x: 0.0, y: 0.0, z: 0.0}}"

# Girar
ros2 topic pub /roborescue/cmd_vel_laptop geometry_msgs/msg/Twist \
    "{linear: {x: 0.0, y: 0.0, z: 0.0}, angular: {x: 0.0, y: 0.0, z: 0.5}}"

# Diagonal + giro
ros2 topic pub /roborescue/cmd_vel_laptop geometry_msgs/msg/Twist \
    "{linear: {x: 0.5, y: 0.3, z: 0.0}, angular: {x: 0.0, y: 0.0, z: 0.2}}"
```

---

## 🔗 Referencias

- **Código:** `src/rpi_relay/rpi_relay/cmd_vel_relay.py`
- **Arquitectura Sistema:** `docs/architecture/ARQUITECTURA_SISTEMA.md`
- **Guía de Pruebas:** `docs/guias/GUIA_PRUEBAS_ROBOT.md`
- **Xbox Controller:** `docs/guias/GUIA_XBOX_CONTROLLER.md`
- **ROS2 Twist:** https://docs.ros.org/en/humble/p/geometry_msgs/
- **micro-ROS:** https://micro.ros.org/

---

## 📝 Notas

- Este nodo es **muy simple** - solo reenvía mensajes sin modificarlos
- **Sin latencia adicional** - simple pass-through
- **Estateless** - no mantiene estado, cada mensaje es independiente
- **Debugging fácil** - monitorea los topics entrada/salida y verás exactamente qué se pasa

---

**Última actualización:** 2026-03-05  
**Equipo:** RoboRescue

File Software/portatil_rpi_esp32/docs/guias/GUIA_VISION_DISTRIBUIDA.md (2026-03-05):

# Sistema de Visión Distribuida - Guía Rápida

⚠️ **NOTA:** Este es el sistema ANTERIOR. El sistema nuevo usa **localización absoluta con homografía**. Ver `GUIA_ROBOT_LOCALIZATION.md` para el sistema actual.

---

## Arquitectura

```
LAPTOP (WiFi)              RPI4 (Ethernet)              ESP32 (USB)
├─ Camera Publisher ────►  (WiFi)                       (Serial /dev/ttyUSB0)
├─ ArUco Detector   ────►                               
└─ Navigator        ────►  Relay Node ────────────────► Motor Control
   /robot1/cmd_vel_laptop  /cmd_vel
```

## Hardware

- **Cámara**: IP Camera (móvil con app IPCamera) - Vista cenital
- **ArUcos**: Robot ID=1, Caja Azul ID=36, Caja Amarilla ID=47
- **Tamaño ArUco**: 5cm (0.05m)
- **ESP32**: Conectado por USB a RPI (/dev/ttyUSB0)

## Uso

### 1. En LAPTOP (Procesamiento de visión)

```bash
cd ~/Desktop/GitHub/pruebas_eurobot
source install/setup.bash

# IMPORTANTE: Configurar ROS_DOMAIN_ID
export ROS_DOMAIN_ID=17

# Opción A: Usar launch file (recomendado)
ros2 launch laptop_vision laptop_vision.launch.py camera_ip:=10.16.250.84:5000 target:=blue_box

# Opción B: Nodos individuales
ros2 run laptop_vision camera_publisher --ros-args -p video_url:=http://10.16.250.84:5000/video
ros2 run laptop_vision aruco_detector
ros2 run laptop_vision aruco_navigator --ros-args -p target:=blue_box
```

### 2. En RPI (Relay + micro-ROS agent)

Terminal 1 - micro-ROS agent:
```bash
cd ~/pruebas_eurobot
source install/setup.bash

# IMPORTANTE: Configurar ROS_DOMAIN_ID
export ROS_DOMAIN_ID=17

ros2 run micro_ros_agent micro_ros_agent serial --dev /dev/ttyUSB0 -b 115200
```

Terminal 2 - Relay node:
```bash
cd ~/pruebas_eurobot
source install/setup.bash

# IMPORTANTE: Configurar ROS_DOMAIN_ID
export ROS_DOMAIN_ID=17

ros2 run rpi_relay cmd_vel_relay
```

### 3. Ver imagen debug (LAPTOP)

```bash
# IMPORTANTE: Configurar ROS_DOMAIN_ID
export ROS_DOMAIN_ID=17

# Opción A: Video con detecciones ArUco y anotaciones (recomendado)
ros2 run rqt_image_view rqt_image_view /roborescue/zenital/debug

# Opción B: Video original sin comprimir (más lag por WiFi)
ros2 run rqt_image_view rqt_image_view /roborescue/zenital/image_raw

# Opción C: Video comprimido (mejor rendimiento en WiFi)
ros2 run rqt_image_view rqt_image_view /roborescue/zenital/image_raw/compressed
```

**Recomendación:** Usa `/compressed` si experimentas lag en el video.

## Topics

### Laptop publica:
- `/roborescue/zenital/image_raw` - Video de cámara sin comprimir (Image)
- `/roborescue/zenital/image_raw/compressed` - Video comprimido (CompressedImage) - **Recomendado para WiFi**
- `/roborescue/zenital/debug` - Video con anotaciones ArUco (Image)
- `/roborescue/robot_pose` - Posición del robot (PoseStamped)
- `/roborescue/blue_box_pose` - Posición de caja azul (PoseStamped)
- `/roborescue/yellow_box_pose` - Posición de caja amarilla (PoseStamped)
- `/roborescue/cmd_vel_laptop` - Comandos de velocidad (Twist)

### RPI relay:
- Suscribe: `/roborescue/cmd_vel_laptop`
- Publica: `/roborescue/cmd_vel` (para ESP32)

### ESP32 suscribe:
- `/roborescue/cmd_vel`

### ESP32 publica:
- `/roborescue/encoder_velocities` - Velocidades de encoders [FL, FR, RL, RR] en RPM (Float32MultiArray)

## Parámetros Ajustables

En `laptop_vision/config/camera.yaml` o por línea de comandos:

```bash
ros2 run laptop_vision aruco_navigator --ros-args \
  -p target:=yellow_box \
  -p max_linear_speed:=0.5 \
  -p max_angular_speed:=1.5 \
  -p linear_p_gain:=0.8 \
  -p angular_p_gain:=2.0 \
  -p goal_tolerance:=0.05
```

## Troubleshooting

Ver problemas comunes y soluciones en: `docs/troubleshooting/`

| Problema | Archivo de referencia |
|---|---|
| No detecta ArUcos | `docs/troubleshooting/aruco-no-detecta.md` |
| Robot no se mueve | `docs/troubleshooting/robot-no-se-mueve.md` |
| micro-ROS no conecta | `docs/troubleshooting/micro-ros-device-busy.md` |

## Configuración Permanente ROS_DOMAIN_ID

Para evitar tener que exportar ROS_DOMAIN_ID=17 en cada terminal:

```bash
# Añadir a ~/.bashrc (tanto en laptop como en RPI)
echo "export ROS_DOMAIN_ID=17" >> ~/.bashrc
source ~/.bashrc
```
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

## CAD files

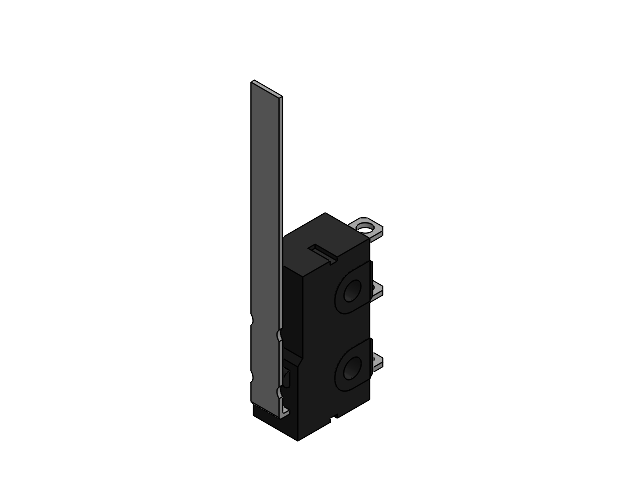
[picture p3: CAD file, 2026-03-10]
Hardware/Componentes/Microswitch.SLDASM
Button.step
Lever.step
Block-0.step
Block-1.step
Block-2.step
Block-3.step

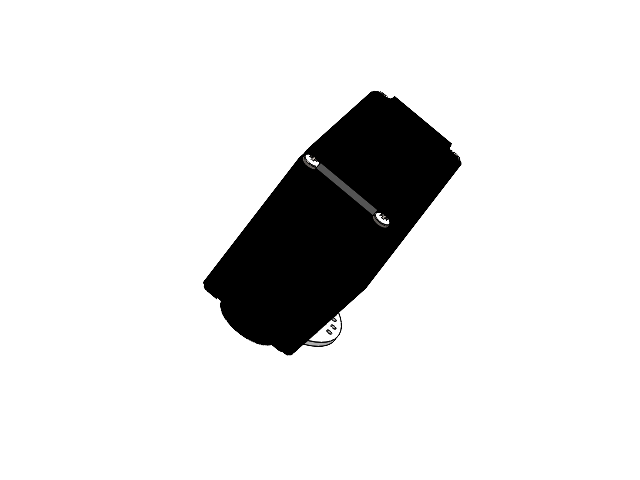
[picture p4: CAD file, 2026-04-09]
Hardware/Componentes/Servos/Hitec HS-311 Servo Motor/Hitec HS-311.SLDASM
Spline
Hitec Servo Motor HS-311
pan head cross recess screw_din x 4

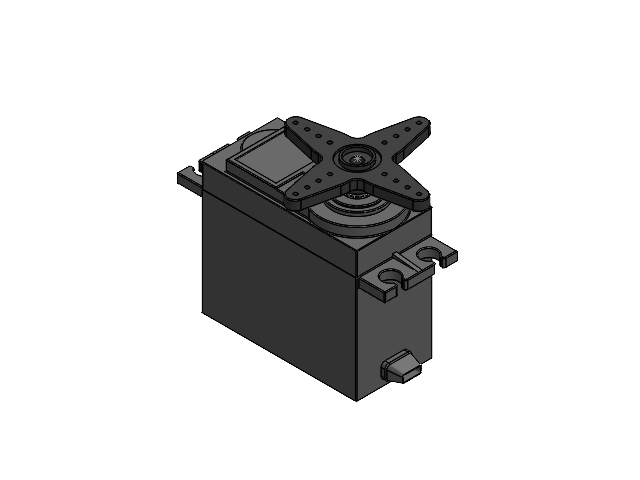
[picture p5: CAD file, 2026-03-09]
Hardware/Componentes/Servos/Servo Futaba S3003 v6.SLDASM
Aspa-creu-Axix holder.step
eBom-FreeParts.step

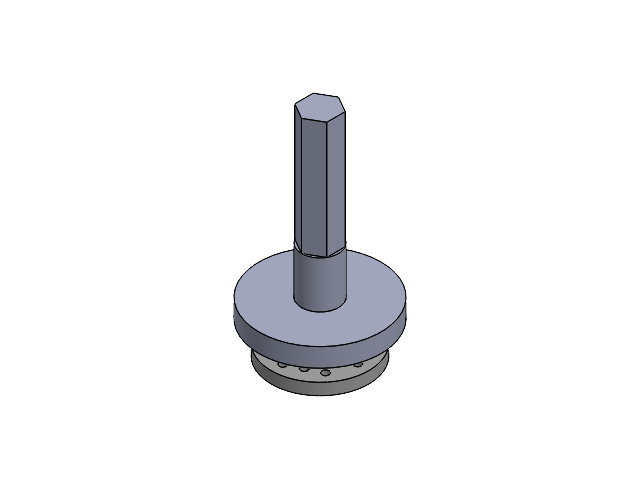
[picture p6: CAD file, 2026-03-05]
Hardware/Componentes/Servos/EnsamblajeSERVO996.SLDASM
Adaptador Servo MG996R
mg996_arm_round

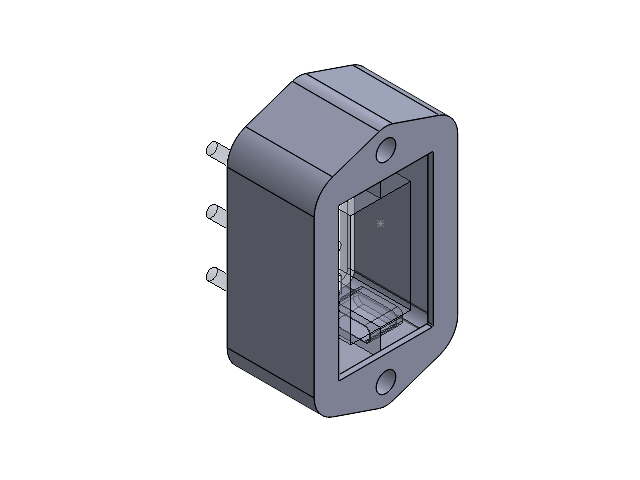
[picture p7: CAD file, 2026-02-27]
Hardware/Modelos 3D/Garra/Ensamblaje soporte servo/Ensamblaje soporte servo.SLDASM
Parte1 SoporteHS311
Parte2 SoporteHS311
Unión de Garra y Mecanismo de Subida

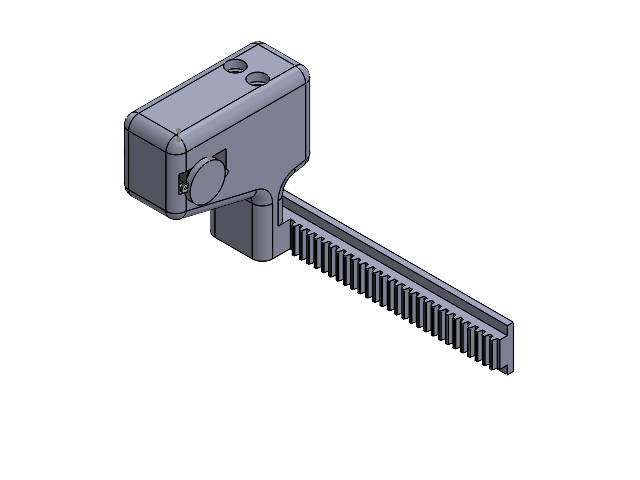
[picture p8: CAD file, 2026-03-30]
Hardware/Modelos 3D/Garra/Garra adaptada/Ensamblaje2.SLDASM
Brazo derecho3
MG90servo_body
MG90servo_shaft
Horn servo sg90
CirculoGarraServo

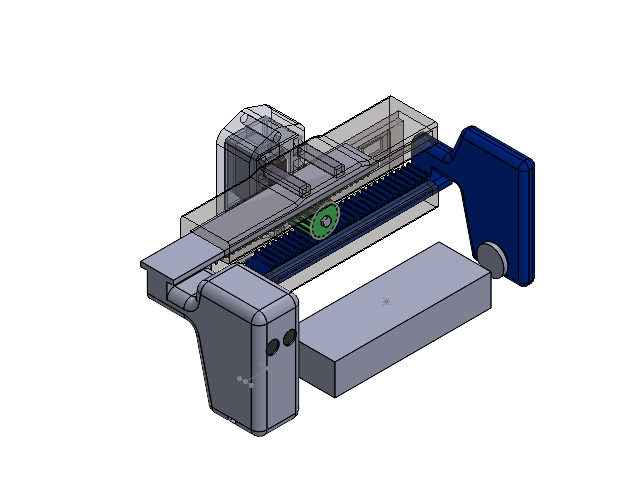
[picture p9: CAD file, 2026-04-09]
Hardware/Modelos 3D/Garra/n20 rack and pinion grippe.SLDASM
ARM MECHANISM N 20 motor 2.0
ARM RIGHT 2.0 n 20 left
engranaje
Brazo derecho3
MG90servo_body
MG90servo_shaft
Horn servo sg90
CirculoGarraServo
CajaBellota
Rodamiento x 2
PiezaGiratoriaRodamiento
rod x 2
Soporte ServoHS311
Unión de Garra y Mecanismo de Subida
mg996R_v2
Circulo mg996R
Adaptador Servo MG996R

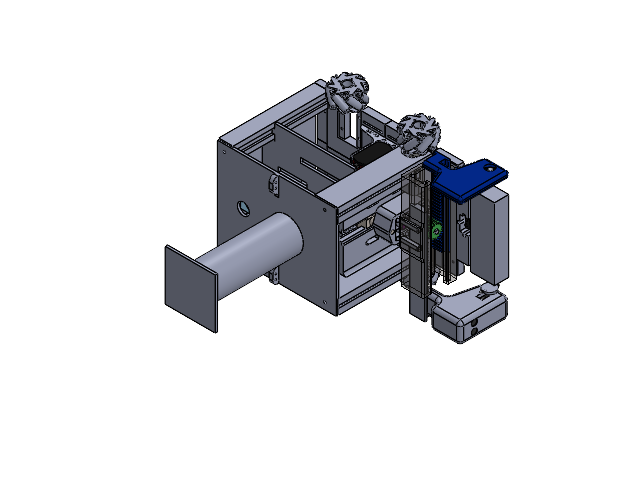
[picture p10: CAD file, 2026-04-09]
Hardware/Modelos 3D/Mecanismo subida garra/Subida_garra_2.SLDASM
Prototipo_Base2
Columna (20cm)V2 x 2
Pololu-25D-12V-21kgcm-DCmotor
cremallera_eurobot
FT5335M Servo Motor
ARM MECHANISM N 20 motor 2.0
ARM RIGHT 2.0 n 20 left
engranaje
Brazo derecho3
MG90servo_body
MG90servo_shaft
Horn servo sg90
CirculoGarraServo
CajaBellota
Rodamiento x 2
PiezaGiratoriaRodamiento
rod x 2
Soporte ServoHS311
Unión de Garra y Mecanismo de Subida
mg996R_v2
Circulo mg996R
Adaptador Servo MG996R
Rueda x 2
gear_eurobot
Plataforma Segunda Planta
Columnas_rARAS2
pared_trasera
Soporte servo FT5355M
Horn FT5335M
Parachoques
Button.step
Lever.step
Block-0.step
Block-1.step
Block-2.step
Block-3.step
Techo
Sostener_Microswitch
MirrorPrototipo_Base2 x 2
MirrorMirrorPrototipo_Base2
MirrorRueda
MirrorMirrorRueda
Mirrorsoporte rueda inferior_prueba3
MirrorColumnas_rARAS2

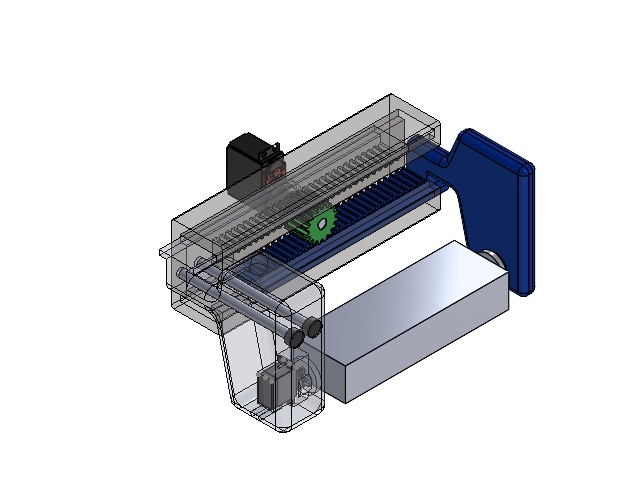
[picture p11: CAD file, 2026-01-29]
Hardware/Modelos 3D/Garra/Garra adaptada/n20 rack and pinion grippe.SLDASM
ARM MECHANISM N 20 motor 2.0
ARM RIGHT 2.0 n 20 left
engranaje
Brazo derecho3
MG90servo_body
MG90servo_shaft
MG90servo_gear
CirculoGarraServo
CajaBellota
Rodamiento x 2
PiezaGiratoriaRodamiento
Spline
Hitec Servo Motor HS-311
pan head cross recess screw_din x 4
rod x 2
Adaptador Servo HS311
PasanteGarraDerecha

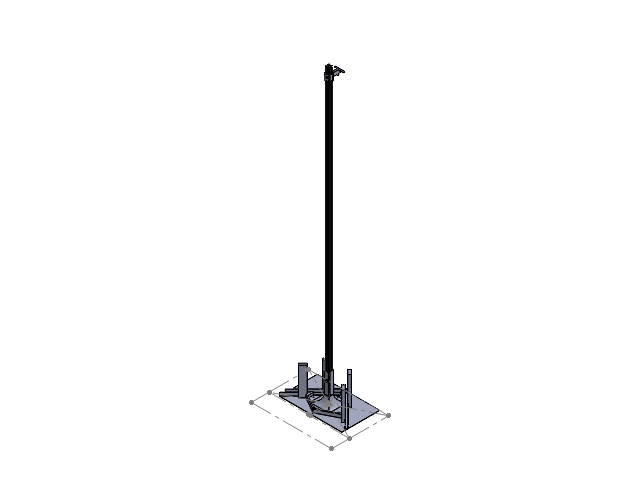
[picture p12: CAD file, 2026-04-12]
Hardware/Modelos 3D/Soporte Cámara/EnsamblajeSoporteCamara.SLDASM
Base Soporte
Centro soporte
V Slot Alu Profile_20x20
Brazo Cámara

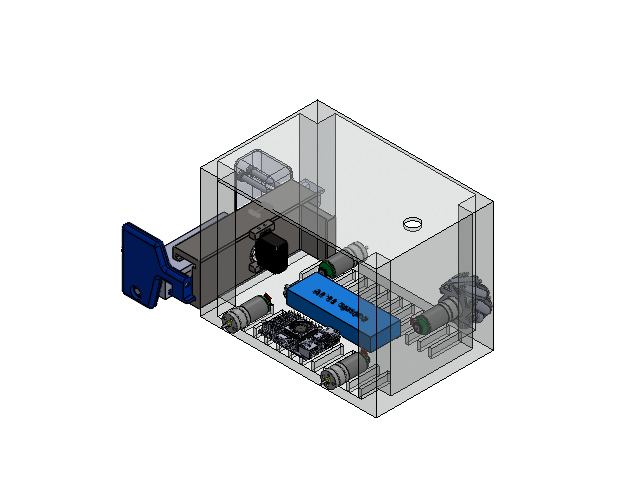
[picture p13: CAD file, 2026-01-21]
Hardware/Modelos 3D/Caja_Ardilla3.0.SLDASM
Chasis
Batería
servo_SG90
CARD_SLOT_METAL_PIN.step
SD_CARD_V1.step
PART3_V1.step
PLATE_RASPBERRY_PI_5.step
METAL_PLATE..step
GIGABIT_ETHERNET_PORT.step
2xUSB_3.0_PORT.step
2xUSB_2.0_PORT.step
FEMALE_MICRO_HDMI_CONNECTOR.step x 2
FEMALE_USB_CONNECTOR.step
STOCK_1.step
STOCK_2.step
STOCK_3.step
3.0_PIN_HEADER_10.step
2.0_PIN_HEADER.step
9FD77_D9WHV.step
GIGABIT_ETHERNET_TRANSCEIVER.step
RP1_CO_CONTROLLER.step
BROADCOM_1.step
MxL.step
CAMERA_DISPLAY_1.step
BUTTON_MINI.step
BUTTON_2.step
CONNECT_V1.step
CAMERA_DISPLAY_2.step x 2
eBom-FreeParts.step
ARM MECHANISM N 20 motor 2.0
ARM RIGHT 2.0 n 20 left
rod x 3
engranaje
Brazo derecho3
MG90servo_body
MG90servo_shaft
MG90servo_gear
CirculoGarraServo
CajaBellota
Rodamiento x 2
PiezaGiratoriaRodamiento
Spline
Hitec Servo Motor HS-311
pan head cross recess screw_din x 4
Adaptador Servo HS311
Pololu-25D-12V-21kgcm-DCmotor x 4
Rueda

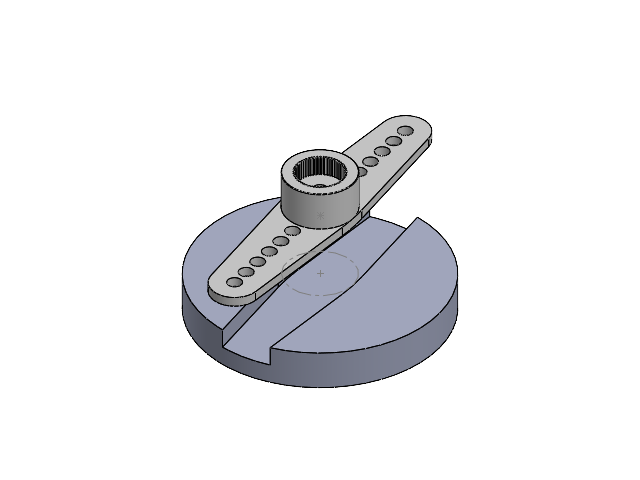
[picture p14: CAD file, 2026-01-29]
Hardware/Modelos 3D/Garra/Garra adaptada/EnsamblajeCirculoGarra.SLDASM
CirculoGarraServo
Horn servo sg90

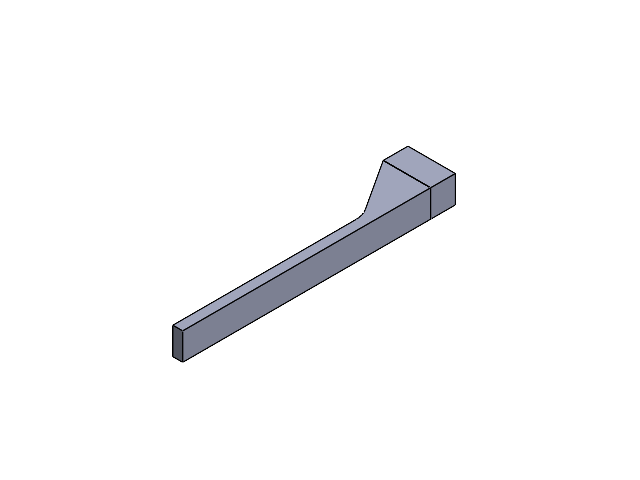
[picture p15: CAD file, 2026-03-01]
Hardware/Modelos 3D/Chasis_Nuevo/Listo para imprimir/Ensamblaje3.SLDASM
Soporte_Planta
Pieza4^Ensamblaje3

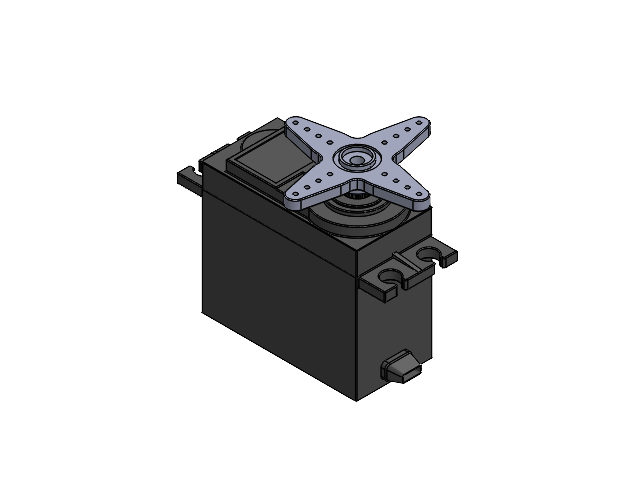
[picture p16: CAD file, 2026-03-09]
Hardware/Modelos 3D/Mecanismo subida garra/Servo Futaba S3003 v6.step.SLDASM
Aspa-creu-Axix holder.step
eBom-FreeParts.step

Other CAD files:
Hardware/Modelos 3D/Chasis_Nuevo/Listo para imprimir/Ensamblaje1.SLDASM
Hardware/Modelos 3D/Chasis_Nuevo/Base_asembly2.SLDASM
Hardware/Modelos 3D/Chasis_Nuevo/Base_asembly.SLDASM
Hardware/Componentes/Batería.SLDPRT
Hardware/Componentes/Raspberry5 y disipador/raspberry-pi-5-stock-active-cooler-1.snapshot.5/RASPBERRY_PI_5+cooler v2.3mf
Hardware/Componentes/Rodamiento.SLDPRT
Hardware/Componentes/Servos/FT5335M Servo Motor.SLDPRT
Hardware/Componentes/Servos/Hitec HS-311 Servo Motor/Hitec Servo Motor HS-311.SLDPRT
Hardware/Componentes/Servos/Hitec HS-311 Servo Motor/Spline 2.SLDPRT
Hardware/Componentes/Servos/Hitec HS-311 Servo Motor/Spline.SLDPRT
Hardware/Componentes/Servos/Servo MG90S/Bidirectional shoulder.SLDPRT
Hardware/Componentes/Servos/Servo MG90S/Bidirectional shoulder.STEP
Hardware/Componentes/Servos/Servo MG90S/Four directed shoulder.STEP
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

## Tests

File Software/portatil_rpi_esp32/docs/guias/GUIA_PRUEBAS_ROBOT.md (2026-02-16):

# Guía de Pruebas del Robot - RoboRescue

## 📋 Resumen de Terminales

### Terminal 1 (SSH a RPI): micro-ROS Agent
```bash
cd ~/Desktop/ros2_pi_esp
source install/setup.bash
ros2 run micro_ros_agent micro_ros_agent serial --dev /dev/ttyUSB0 -b 115200
```

**Salida esperada:**
```
[INFO] [micro_ros_agent]: Serial port: /dev/ttyUSB0
[INFO] [micro_ros_agent]: Running...
[INFO] [TermiosAgentLinux.cpp:228] info | Root.cpp | create_client | create | client_key: 0x...
```

---

### Terminal 2 (SSH a RPI): Comandos de Prueba y Verificación
```bash
cd ~/Desktop/ros2_pi_esp
source install/setup.bash

# Verificar nodos activos
ros2 node list
# Deberías ver: /roborescue/esp32_mecanum

# Verificar tópicos disponibles
ros2 topic list
# Deberías ver: /roborescue/cmd_vel, /parameter_events, /rosout

# Ver información del tópico
ros2 topic info /roborescue/cmd_vel

# Monitorear mensajes en tiempo real (opcional)
ros2 topic echo /roborescue/cmd_vel
```

---

## 🎮 Comandos Completos de Prueba

> **IMPORTANTE:** Ahora el sistema usa namespace `/roborescue/`. Existen dos formas de enviar comandos:
> 1. **Con namespace completo**: `/roborescue/cmd_vel` (recomendado para pruebas directas)
> 2. **Sin namespace**: `/cmd_vel` (deprecated, solo para compatibilidad)

### Prueba 0: Parar motores (SIEMPRE PRIMERO)

**Con namespace (recomendado):**
```bash
ros2 topic pub --once /roborescue/cmd_vel geometry_msgs/msg/Twist "{linear: {x: 0.0, y: 0.0, z: 0.0}, angular: {x: 0.0, y: 0.0, z: 0.0}}"
```

**Sin namespace (deprecated):**
```bash
ros2 topic pub --once /cmd_vel geometry_msgs/msg/Twist "{linear: {x: 0.0, y: 0.0, z: 0.0}, angular: {x: 0.0, y: 0.0, z: 0.0}}"
```

---

### Prueba 1: Avanzar hacia adelante (100% velocidad)

**Con namespace (recomendado):**
```bash
ros2 topic pub --once /roborescue/cmd_vel geometry_msgs/msg/Twist "{linear: {x: 1.0, y: 0.0, z: 0.0}, angular: {x: 0.0, y: 0.0, z: 0.0}}"
```

**Sin namespace (deprecated):**
```bash
ros2 topic pub --once /cmd_vel geometry_msgs/msg/Twist "{linear: {x: 1.0, y: 0.0, z: 0.0}, angular: {x: 0.0, y: 0.0, z: 0.0}}"
```
**Resultado esperado:** Los 4 motores giran hacia adelante. El robot avanza.

**Nota:** L298N necesita voltaje alto para vencer la inercia inicial. Si es muy rápido, prueba con 0.8.

---

### Prueba 2: Retroceder (100% velocidad)

**Con namespace (recomendado):**
```bash
ros2 topic pub --once /roborescue/cmd_vel geometry_msgs/msg/Twist "{linear: {x: -1.0, y: 0.0, z: 0.0}, angular: {x: 0.0, y: 0.0, z: 0.0}}"
```

**Sin namespace (deprecated):**
```bash
ros2 topic pub --once /cmd_vel geometry_msgs/msg/Twist "{linear: {x: -1.0, y: 0.0, z: 0.0}, angular: {x: 0.0, y: 0.0, z: 0.0}}"
```

**Resultado esperado:** El robot retrocede.

---

### Prueba 3: Giro horario sobre sí mismo (100% velocidad)

**Con namespace (recomendado):**
```bash
ros2 topic pub --once /roborescue/cmd_vel geometry_msgs/msg/Twist "{linear: {x: 0.0, y: 0.0, z: 0.0}, angular: {x: 0.0, y: 0.0, z: 1.0}}"
```

**Sin namespace (deprecated):**
```bash
ros2 topic pub --once /cmd_vel geometry_msgs/msg/Twist "{linear: {x: 0.0, y: 0.0, z: 0.0}, angular: {x: 0.0, y: 0.0, z: 1.0}}"
```

**Resultado esperado:** El robot gira en sentido horario sobre su eje central.

---

### Prueba 4: Giro antihorario sobre sí mismo (100% velocidad)

**Con namespace (recomendado):**
```bash
ros2 topic pub --once /roborescue/cmd_vel geometry_msgs/msg/Twist "{linear: {x: 0.0, y: 0.0, z: 0.0}, angular: {x: 0.0, y: 0.0, z: -1.0}}"
```

**Sin namespace (deprecated):**
```bash
ros2 topic pub --once /cmd_vel geometry_msgs/msg/Twist "{linear: {x: 0.0, y: 0.0, z: 0.0}, angular: {x: 0.0, y: 0.0, z: -1.0}}"
```

**Resultado esperado:** El robot gira en sentido antihorario sobre su eje central.

---

### Prueba 5: Desplazamiento lateral derecha (Mecanum - 100%)

**Con namespace (recomendado):**
```bash
ros2 topic pub --once /roborescue/cmd_vel geometry_msgs/msg/Twist "{linear: {x: 0.0, y: 1.0, z: 0.0}, angular: {x: 0.0, y: 0.0, z: 0.0}}"
```

**Sin namespace (deprecated):**
```bash
ros2 topic pub --once /cmd_vel geometry_msgs/msg/Twist "{linear: {x: 0.0, y: 1.0, z: 0.0}, angular: {x: 0.0, y: 0.0, z: 0.0}}"
```

**Resultado esperado:** El robot se desplaza lateralmente hacia la derecha sin cambiar orientación.

---

### Prueba 6: Desplazamiento lateral izquierda (Mecanum - 100%)

**Con namespace (recomendado):**
```bash
ros2 topic pub --once /roborescue/cmd_vel geometry_msgs/msg/Twist "{linear: {x: 0.0, y: -1.0, z: 0.0}, angular: {x: 0.0, y: 0.0, z: 0.0}}"
```

**Sin namespace (deprecated):**
```bash
ros2 topic pub --once /cmd_vel geometry_msgs/msg/Twist "{linear: {x: 0.0, y: -1.0, z: 0.0}, angular: {x: 0.0, y: 0.0, z: 0.0}}"
```

**Resultado esperado:** El robot se desplaza lateralmente hacia la izquierda sin cambiar orientación.

---

### Prueba 7: Movimiento diagonal (adelante + derecha - 80%)

**Con namespace (recomendado):**
```bash
ros2 topic pub --once /roborescue/cmd_vel geometry_msgs/msg/Twist "{linear: {x: 0.8, y: 0.8, z: 0.0}, angular: {x: 0.0, y: 0.0, z: 0.0}}"
```

**Sin namespace (deprecated):**
```bash
ros2 topic pub --once /cmd_vel geometry_msgs/msg/Twist "{linear: {x: 0.8, y: 0.8, z: 0.0}, angular: {x: 0.0, y: 0.0, z: 0.0}}"
```

**Resultado esperado:** El robot se mueve en diagonal (45°) hacia adelante-derecha.

**Nota:** Velocidad reducida a 80% en movimientos combinados para mantener el control.

---

### Prueba 8: Movimiento combinado (adelante + giro - 80%)

**Con namespace (recomendado):**
```bash
ros2 topic pub --once /roborescue/cmd_vel geometry_msgs/msg/Twist "{linear: {x: 0.8, y: 0.0, z: 0.0}, angular: {x: 0.0, y: 0.0, z: 0.6}}"
```

**Sin namespace (deprecated):**
```bash
ros2 topic pub --once /cmd_vel geometry_msgs/msg/Twist "{linear: {x: 0.8, y: 0.0, z: 0.0}, angular: {x: 0.0, y: 0.0, z: 0.6}}"
```

**Resultado esperado:** El robot avanza mientras gira (trayectoria curva).

---

### Prueba 9: Modo continuo (mantener movimiento hasta Ctrl+C)

**Con namespace (recomendado):**
```bash
# Quitar --once para envío continuo
ros2 topic pub /roborescue/cmd_vel geometry_msgs/msg/Twist "{linear: {x: 1.0, y: 0.0, z: 0.0}, angular: {x: 0.0, y: 0.0, z: 0.0}}"
```

**Sin namespace (deprecated):**
```bash
ros2 topic pub /cmd_vel geometry_msgs/msg/Twist "{linear: {x: 1.0, y: 0.0, z: 0.0}, angular: {x: 0.0, y: 0.0, z: 0.0}}"
```

**Nota:** Presiona `Ctrl+C` para detener el envío continuo, luego envía comando de PARAR.

---

### Prueba 10: Velocidad media (si 1.0 es muy rápido)

**Con namespace (recomendado):**
```bash
ros2 topic pub --once /roborescue/cmd_vel geometry_msgs/msg/Twist "{linear: {x: 0.8, y: 0.0, z: 0.0}, angular: {x: 0.0, y: 0.0, z: 0.0}}"
```

**Sin namespace (deprecated):**
```bash
ros2 topic pub --once /cmd_vel geometry_msgs/msg/Twist "{linear: {x: 0.8, y: 0.0, z: 0.0}, angular: {x: 0.0, y: 0.0, z: 0.0}}"
```
**Nota:** Usa 0.8 para velocidad controlada si 1.0 es demasiado rápido.

---

## 📖 Explicación del Mensaje Twist

### Estructura del mensaje `geometry_msgs/msg/Twist`

```yaml
linear:
  x: float64  # Velocidad lineal en eje X (adelante/atrás)
  y: float64  # Velocidad lineal en eje Y (derecha/izquierda) - SOLO Mecanum/Omni
  z: float64  # Velocidad lineal en eje Z (arriba/abajo) - No usado en robots terrestres

angular:
  x: float64  # Velocidad angular en eje X (pitch) - No usado
  y: float64  # Velocidad angular en eje Y (roll) - No usado
  z: float64  # Velocidad angular en eje Z (yaw/giro sobre sí mismo)
```

---

### Rangos de Valores

| Campo | Rango | Descripción |
|---|---|---|
| `linear.x` | `-1.0` a `1.0` | **Positivo:** Adelante<br>**Negativo:** Atrás<br>**0.0:** Sin movimiento |
| `linear.y` | `-1.0` a `1.0` | **Positivo:** Derecha<br>**Negativo:** Izquierda<br>**0.0:** Sin movimiento lateral |
| `linear.z` | `0.0` | No usado en robots terrestres |
| `angular.x` | `0.0` | No usado |
| `angular.y` | `0.0` | No usado |
| `angular.z` | `-1.0` a `1.0` | **Positivo:** Giro horario<br>**Negativo:** Giro antihorario<br>**0.0:** Sin rotación |

---

### Ejemplos Prácticos

#### Movimiento Simple
```yaml
# Avanzar al 50%
linear: {x: 0.5, y: 0.0, z: 0.0}
angular: {x: 0.0, y: 0.0, z: 0.0}

# Retroceder al 30%
linear: {x: -0.3, y: 0.0, z: 0.0}
angular: {x: 0.0, y: 0.0, z: 0.0}

# Derecha al 40%
linear: {x: 0.0, y: 0.4, z: 0.0}
angular: {x: 0.0, y: 0.0, z: 0.0}

# Giro horario al 50%
linear: {x: 0.0, y: 0.0, z: 0.0}
angular: {x: 0.0, y: 0.0, z: 0.5}
```

#### Movimientos Combinados
```yaml
# Diagonal: adelante + derecha
linear: {x: 0.5, y: 0.5, z: 0.0}
angular: {x: 0.0, y: 0.0, z: 0.0}

# Curva: adelante + giro
linear: {x: 0.5, y: 0.0, z: 0.0}
angular: {x: 0.0, y: 0.0, z: 0.3}

# Complejo: diagonal + giro
linear: {x: 0.4, y: 0.3, z: 0.0}
angular: {x: 0.0, y: 0.0, z: 0.2}
```

---

## 🔧 Fórmulas de Control Mecanum (Referencia)

### Configuración del Robot Casa
Según el código en `esp32_casa/src/main.cpp`:

```cpp
// Fórmulas para ruedas Mecanum (configuración X)
float speed_fl = x - y - z;  // Frontal Izquierda (Motor 2)
float speed_fr = x + y + z;  // Frontal Derecha (Motor 3)
float speed_rl = x + y - z;  // Trasera Izquierda (Motor 0)
float speed_rr = x - y + z;  // Trasera Derecha (Motor 1)

Donde:
  x = msg->linear.x   (adelante/atrás)
  y = msg->linear.y   (derecha/izquierda)
  z = msg->angular.z  (giro)
```

### Tabla de Movimientos

| Movimiento | x | y | z | FL | FR | RL | RR |
|---|---|---|---|----|----|----|----|
| Adelante | + | 0 | 0 | +  | +  | +  | +  |
| Atrás | - | 0 | 0 | -  | -  | -  | -  |
| Derecha | 0 | + | 0 | -  | +  | +  | -  |
| Izquierda  | 0 | - | 0 | +  | -  | -  | +  |
| Giro Horario | 0 | 0 | + | -  | +  | -  | +  |
| Giro Antihorario| 0 | 0 | - | +  | -  | +  | -  |

---

## 🚀 Secuencia Recomendada para Primera Prueba

1. **Verificar conexión física:**
   - ESP32 alimentado
   - USB conectado a RPI
   - Batería de L298N conectada
   - Motores conectados

2. **Ejecutar micro-ROS agent** (Terminal 1)

3. **Verificar comunicación** (Terminal 2):
   ```bash
   ros2 node list
   ros2 topic list
   ```

4. **Probar movimientos básicos** (en orden):
   - Prueba 0: PARAR (seguridad)
   - Prueba 1: Avanzar
   - Prueba 0: PARAR
   - Prueba 3: Giro
   - Prueba 0: PARAR
   - Prueba 5: Lateral derecha
   - Prueba 0: PARAR

5. **Ajustar si es necesario:**
   - Si un motor gira al revés, invertir cables o modificar código
   - Si la velocidad es muy alta/baja, ajustar los valores

---

## ⚠️ Notas de Seguridad

- **SIEMPRE** ten el comando de PARAR listo para copiar/pegar
- Realiza las primeras pruebas con el robot **elevado** (sin tocar el suelo)
- Los drivers **L298N necesitan voltajes altos** (1.0 o 0.8) para vencer la inercia inicial debido a su caída de voltaje (~2V)
- Con 0.3 o valores bajos, los motores solo zumban sin moverse (voltaje insuficiente)
- Ten espacio libre de al menos 2x2 metros para pruebas en el suelo
- Mantén el botón de emergencia (si lo hay) accesible
- Ten una mano cerca del cable de alimentación para desconectar rápidamente si es necesario

---

## 📊 Registro de Pruebas

### Robot Casa - L298N

| Fecha | Prueba | Resultado | Observaciones |
|---|---|---|---|
| 2026-02-07 | Freno | ✅ OK | Motores se detienen correctamente |
| 2026-02-07 | Avance frontal (0.3) | ⚠️ Insuficiente | Motores zumban pero no se mueven - voltaje insuficiente |
| 2026-02-07 | Avance frontal (1.0) | ✅ OK | Robot avanza correctamente con velocidad alta |
| | | | |

**Conclusión:** L298N requiere velocidades altas (0.8-1.0) debido a caída de voltaje del driver (~2V).

---

## 🔗 Referencias

- Código ESP32 Casa: `esp32_casa/src/main.cpp`
- Especificaciones Hardware: `docs/hardware/ESPECIFICACIONES_HARDWARE.md`
- Comparativa Robots: `docs/hardware/COMPARATIVA_ROBOTS.md`
- Arquitectura Sistema: `docs/architecture/ARQUITECTURA_SISTEMA.md`

---

## 📝 Notas de Actualización

### Cambio de Namespace (2026-02-12)

El sistema ha sido actualizado para usar el namespace `/roborescue/` en lugar de `/robot1/`:

**Antes (deprecated):**
- Nodo: `/microros_esp32_omni`
- Topic: `/cmd_vel`

**Ahora (actual):**
- Nodo: `/roborescue/esp32_mecanum`
- Topic: `/roborescue/cmd_vel`
- ROS_DOMAIN_ID: 17 (configurado en ESP32, RPI y laptop)

**Ventajas del nuevo sistema:**
- ✅ Namespace consistente para competición multi-robot
- ✅ Domain ID 17 configurado para evitar interferencias
- ✅ Preparado para integración con sistema de visión
- ✅ Soporte para futuros sensores y actuadores

**Compatibilidad:**
Los comandos antiguos sin namespace (`/cmd_vel`) siguen funcionando por compatibilidad, pero se recomienda usar el namespace completo (`/roborescue/cmd_vel`) para todas las pruebas nuevas.

---

**Última actualización:** 2026-02-12  
**Autor:** Team RoboRescue

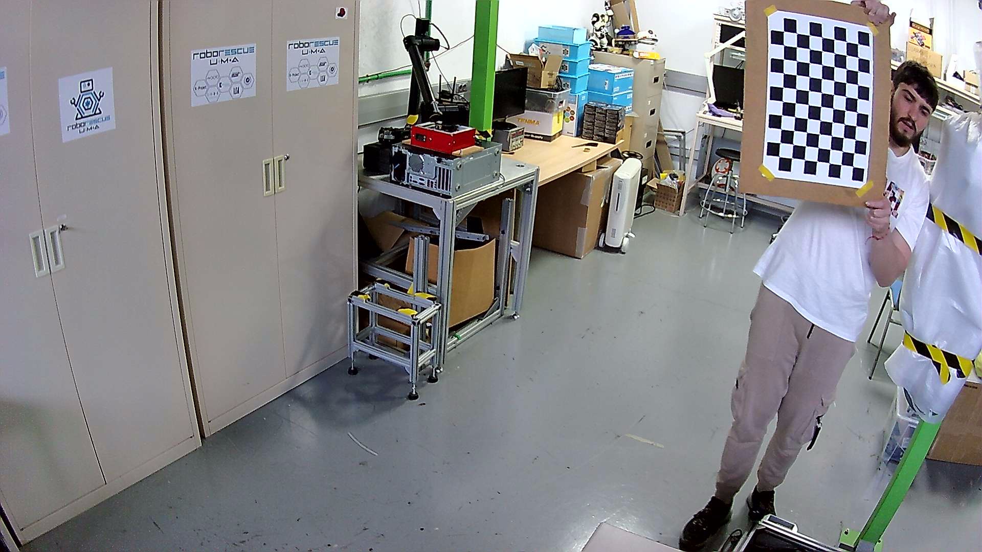
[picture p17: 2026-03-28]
Software/Visión Arucos/fotos_calibracion2/foto_036.jpg

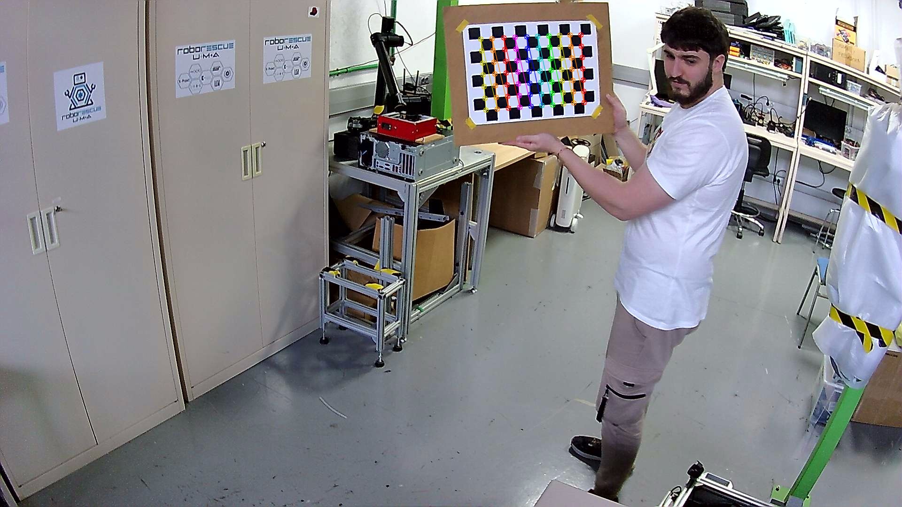
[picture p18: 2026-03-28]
Software/Visión Arucos/fotos_calibracion_detectadas2/foto_030.jpg

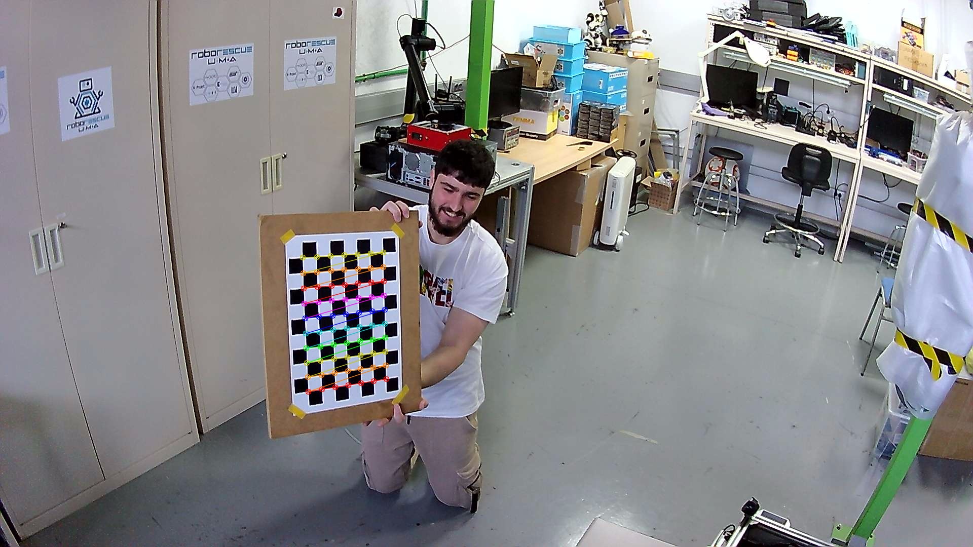
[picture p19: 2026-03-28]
Software/Visión Arucos/fotos_calibracion_detectadas2/foto_025.jpg

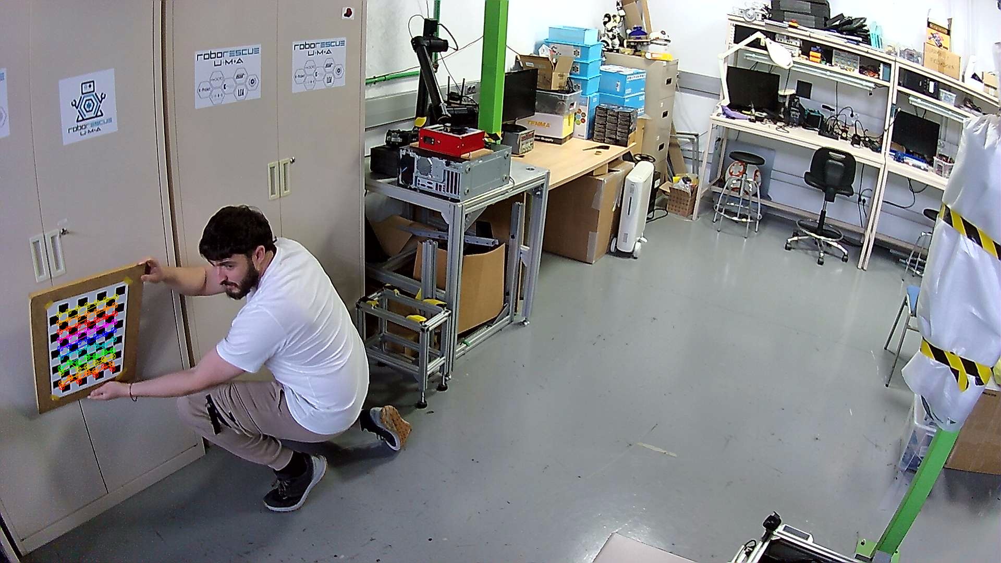
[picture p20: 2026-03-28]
Software/Visión Arucos/fotos_calibracion_detectadas2/foto_008.jpg

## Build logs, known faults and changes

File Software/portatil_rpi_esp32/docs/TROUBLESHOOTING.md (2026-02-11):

# Troubleshooting - Registro de Problemas

## 🤖 Robot Casa - L298N

### 2026-02-07: Motor 3 no retrocede

**Síntoma:** Motor avanza pero no retrocede (zumba sin moverse)

**Causa:** GPIO 16/17 son pines UART2 (RX2/TX2) con restricciones hardware

**Solución:** Cambio de pines Motor 3
```cpp
// ANTES
#define M3_IN3 16 // RX2
#define M3_IN4 17 // TX2

// DESPUÉS
#define M3_IN3 18 // GPIO propósito general
#define M3_IN4 19 // GPIO propósito general
```

**Resultado:** ✅ Motor funciona en ambas direcciones. GPIOs 18/19 libres de restricciones.

**Acción:** Reconectar cables + recompilar firmware

---

### 2026-02-07: L298N requiere velocidades altas

**Síntoma:** Con velocidad 0.3 motores zumban pero no se mueven

**Causa:** L298N tiene caída de voltaje ~2V. PWM bajo no genera torque suficiente.

**Solución:** Usar velocidades mínimas 0.8-1.0 (80-100%)

**Resultado:** ✅ Movimiento correcto con velocidades altas

---

## 📝 Referencia Rápida

### GPIOs ESP32 para motores

**❌ Evitar:**
- GPIO 0, 2, 15 (boot)
- GPIO 1, 3 (Serial)
- GPIO 6-11 (Flash)
- GPIO 16, 17 (UART2)

**✅ Recomendados:**
- GPIO 18, 19, 21, 22, 23
- GPIO 25, 26, 27, 32, 33
- GPIO 4, 5, 12, 13, 14

### Drivers

**L298N:** Requiere velocidades >0.8 (caída 2V)  
**DFRobot:** Funciona con velocidades >0.3 (menor caída)

---

**Última actualización:** 2026-02-07

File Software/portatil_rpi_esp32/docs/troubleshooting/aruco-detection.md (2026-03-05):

# Troubleshooting - Detección ArUco (robot_localization)

## 🔍 Problemas Comunes de Detección ArUco

Este documento cubre problemas específicos de detección de marcadores ArUco en el sistema de localización basado en homografía.

**Sistema:** `robot_localization/field_localizer.py`  
**Referencias:** Ver `docs/guias/GUIA_ROBOT_LOCALIZATION.md`

---

## ⚠️ ArUcos No Son Detectados

### Síntomas
- El nodo `field_localizer` corre pero no detecta ningún ArUco
- Topic `/roborescue/robot_pose` no publica datos
- Logs muestran: "No ArUcos detected" o similar

### Causas Comunes

#### 1. **Problemas de Iluminación**

**Síntomas:** Los ArUcos son visibles pero el detector no los ve

**Soluciones:**
```bash
# Aumentar brillo de la cámara (si es cámara IP)
# O mejorar iluminación ambiental

# Verificar imagen cruda
ros2 run image_view image_view image:=/roborescue/zenital/image_raw

# Buscar marcadores negros/blancos claramente diferenciados
```

**Ajustes recomendados:**
- Coloca luces LED de 5000K a 6500K sobre el campo
- Evita sombras sobre los marcadores
- Asegura que el contraste blanco/negro es visible

---

#### 2. **Tamaño de ArUco Incorrecto**

**Síntomas:** ArUcos presentes pero no detectados

**Soluciones:**
```bash
# Verificar tamaño mínimo en field_localizer.py:
# min_marker_pixels = 50  # píxeles cuadrados mínimos

# Si ArUcos son demasiado pequeños:
# - Acerca la cámara más al campo
# - Usa lentes de mayor ángulo si es posible
# - Aumenta el tamaño de los ArUcos impresos

# Si ArUcos son detectados pero inconsistentes:
min_marker_pixels = 30  # Reduce este valor
```

**Tamaño recomendado:**
- Impresos en papel: 10cm × 10cm (mínimo 8cm)
- En campo de 300×200cm con cámara zenital

---

#### 3. **Diccionario ArUco Incorrecto**

**Síntomas:** Algunos ArUcos se detectan, otros no

**Soluciones:**
```python
# Verificar en field_localizer.py línea ~30:
# dictionary = cv2.aruco.getPredefinedDictionary(cv2.aruco.DICT_6X6_250)

# Opciones disponibles:
# - DICT_4X4_50      (0-49, pequeños)
# - DICT_5X5_100     (0-99)
# - DICT_6X6_250     (0-249, recomendado) ← ACTUAL
# - DICT_7X7_1000    (0-999, grandes)

# Cambiar diccionario si es necesario:
dictionary = cv2.aruco.getPredefinedDictionary(cv2.aruco.DICT_5X5_100)
```

**IDs disponibles según diccionario:**
- ArUcos 20, 21, 22, 23 (esquinas) ✅ válidos en DICT_6X6_250
- ArUco 1 (robot) ✅ válido
- ArUco 36, 47 (cajas) ✅ válidos

---

#### 4. **Deformación Óptica (Distorsión de Cámara)**

**Síntomas:** ArUcos detectados pero posiciones incorrectas/saltando

**Soluciones:**
```bash
# Calibrar cámara (proceso de una sola vez)
# Usar patrón de tablero de ajedrez para calibrar distorsión

# Archivo de calibración debería estar en:
# config/camera_calibration.yaml

# Si no existe, crear uno:
# (Ver sección "Calibración de Cámara" abajo)

# En field_localizer.py, cargar calibración:
# with open('config/camera_calibration.yaml') as f:
#     calib = yaml.safe_load(f)
#     mtx = np.array(calib['camera_matrix']['data']).reshape(3, 3)
#     dist = np.array(calib['distortion_coefficients']['data'])
#     frame = cv2.undistort(frame, mtx, dist)
```

---

#### 5. **IDs de ArUco Incorrectos o Duplicados**

**Síntomas:** 
- Algunos ArUcos no se usan en posiciones
- Errores de homografía o outliers

**Soluciones:**
```python
# Verificar IDs en field_localizer.py (línea ~40):
REFERENCE_MARKERS = {
    20: (0, 0),       # Esquina superior izquierda ✅
    21: (300, 0),     # Esquina superior derecha ✅
    22: (0, 200),     # Esquina inferior izquierda ✅
    23: (300, 200)    # Esquina inferior derecha ✅
}

# Verificar que no hay duplicados
# Verificar que los IDs coinciden con los ArUcos impresos

# Para verificar qué ArUcos se detectan en tiempo real:
# (Ver sección "Verificación en Tiempo Real")
```

**Tabla de IDs configurados:**

| ID | Posición | Campo | Estado |
|----|---|---|---|
| 20 | (0, 0) | Esquina TL | ✅ Referencia |
| 21 | (300, 0) | Esquina TR | ✅ Referencia |
| 22 | (0, 200) | Esquina BL | ✅ Referencia |
| 23 | (300, 200) | Esquina BR | ✅ Referencia |
| 1 | Variable | Robot | ✅ Móvil |
| 36 | Variable | Caja Azul | ✅ Móvil |
| 47 | Variable | Caja Amarilla | ✅ Móvil |

---

## 📍 Homografía No Converge / Posiciones Incorrectas

### Síntomas
- Posiciones aleatorias o muy saltando
- Pose2D publica valores inconsistentes
- Errores de reproyección altos

### Causas y Soluciones

#### 1. **Menos de 4 Marcadores de Referencia Visibles**

**Síntomas:** 
- Logs muestran "< 4 reference markers"
- Homografía se reutiliza indefinidamente

**Soluciones:**
```bash
# Reposicionar cámara para ver los 4 ArUcos de esquina
# Asegurar que toda el área del campo es visible

# Aumentar altura de cámara zenital si es necesario
# Reducir ángulo si hay perspectiva distorsionada

# Verificar en tiempo real:
ros2 topic echo /roborescue/robot_pose
# Si no cambia o muestra "NaN", problema de homografía
```

---

#### 2. **Homografía Mal Calculada (Outliers)**

**Síntomas:**
- Algunos puntos se detectan pero dan posiciones absurdas
- Posiciones "saltando" entre correctas e incorrectas

**Soluciones:**
```python
# En field_localizer.py, línea ~150 (homografía):
# Usar RANSAC para filtrar outliers

h, mask = cv2.findHomography(src_pts, dst_pts, cv2.RANSAC, 5.0)

# Aumentar umbral si hay demasiados outliers:
h, mask = cv2.findHomography(src_pts, dst_pts, cv2.RANSAC, 10.0)

# Reducir si hay demasiados falsos positivos:
h, mask = cv2.findHomography(src_pts, dst_pts, cv2.RANSAC, 2.0)

# Verificar calidad de la homografía:
print(f"Homografía válida: {h is not None}")
print(f"Rango de valores: {np.min(h):.4f} a {np.max(h):.4f}")
```

---

#### 3. **Orden de Coordenadas Incorrecto**

**Síntomas:**
- Posiciones X e Y invertidas
- Robot reporta estar fuera del campo

**Verificación:**
```bash
# Mover robot a esquina conocida (ej: (0,0))
# Verificar que topic reporta cerca de (0, 0)

# Si reporta (300, 200) cuando debería ser (0, 0):
# Las esquinas están rotadas en el código

# Solución: Revisar mapping en field_localizer.py:
REFERENCE_MARKERS = {
    20: (0, 0),       # DEBE ser esquina superior izquierda
    21: (300, 0),     # DEBE ser esquina superior derecha
}
# Verificar que coincide con posición física real
```

---

## 🎥 Verificación en Tiempo Real

### Script para Diagnóstico

```python
# Crear archivo: verify_aruco.py

import rclpy
from rclpy.node import Node
from sensor_msgs.msg import Image
from cv_bridge import CvBridge
import cv2
import numpy as np

class ArUcoVerifier(Node):
    def __init__(self):
        super().__init__('aruco_verifier')
        self.sub = self.create_subscription(Image, '/roborescue/zenital/image_raw', self.callback, 10)
        self.bridge = CvBridge()
        self.dictionary = cv2.aruco.getPredefinedDictionary(cv2.aruco.DICT_6X6_250)
        self.detector = cv2.aruco.ArucoDetector(self.dictionary)

    def callback(self, msg):
        frame = self.bridge.imgmsg_to_cv2(msg, "bgr8")
        corners, ids, rejected = self.detector.detectMarkers(frame)
        
        if ids is not None:
            self.get_logger().info(f"✅ Detectados {len(ids)} ArUcos: {ids.flatten().tolist()}")
            frame = cv2.aruco.drawDetectedMarkers(frame, corners, ids)
        else:
            self.get_logger().warn("❌ No ArUcos detected")
        
        # Mostrar frame
        cv2.imshow("ArUco Detection", frame)
        cv2.waitKey(1)

def main(args=None):
    rclpy.init(args=args)
    node = ArUcoVerifier()
    rclpy.spin(node)

if __name__ == '__main__':
    main()
```

**Ejecutar:**
```bash
python3 verify_aruco.py
# Mostrará ventana con ArUcos detectados
# Logs mostrarán IDs detectados en tiempo real
```

---

## 🔧 Calibración de Cámara

### Problema
Si la cámara tiene distorsión óptica, las posiciones serán inexactas.

### Solución: Calibrar Cámara

#### 1. Capturar Imágenes de Calibración
```bash
# Imprimir patrón de tablero de ajedrez (8x6, 30mm cuadrados)
# https://docs.opencv.org/4.x/da/d0d/tutorial_camera_calibration_pattern.html

# Capturar 20-30 imágenes del patrón desde diferentes ángulos
ros2 run camera_calibration cameracalibrator.py --size 8x6 --square 0.03 image:=/roborescue/zenital/image_raw camera:=/camera

# Los archivos se guardarán en ~/.ros/
```

#### 2. Generar Archivo de Calibración
```bash
# El archivo generado contiene:
# - camera_matrix (matriz de intrínsecos)
# - distortion_coefficients (coeficientes de distorsión)

# Guardar en: src/robot_localization/config/camera_calibration.yaml
```

#### 3. Usar Calibración en field_localizer.py
```python
import yaml

with open('config/camera_calibration.yaml') as f:
    calib = yaml.safe_load(f)
    mtx = np.array(calib['camera_matrix']['data']).reshape(3, 3)
    dist = np.array(calib['distortion_coefficients']['data'])

# En el callback de imagen:
frame = cv2.undistort(frame, mtx, dist)  # Deshacer distorsión
```

---

## 🐛 Debugging Avanzado

### Activar Logs Detallados
```bash
# Nivel DEBUG
ros2 run robot_localization field_localizer --ros-args --log-level DEBUG

# Nivel WARN (menos verbose)
ros2 run robot_localization field_localizer --ros-args --log-level WARN
```

### Guardar Frames para Análisis Offline
```python
# En field_localizer.py, agregar después de detectar ArUcos:
if ids is not None:
    frame_with_markers = cv2.aruco.drawDetectedMarkers(frame.copy(), corners, ids)
    cv2.imwrite(f'/tmp/frame_{frame_count}.jpg', frame_with_markers)
```

### Verificar Transformación de Coordenadas
```bash
# Crear pequeño test script
python3 -c "
import numpy as np
import cv2

# Puntos de prueba en imagen (píxeles)
img_pts = np.array([[50, 50], [250, 50], [50, 150], [250, 150]], dtype=np.float32)

# Puntos en campo (cm)
field_pts = np.array([[0, 0], [300, 0], [0, 200], [300, 200]], dtype=np.float32)

# Calcular homografía
H, _ = cv2.findHomography(img_pts, field_pts)

# Prueba: transformar punto (50, 50) en imagen
test_pt = np.array([[[50, 50]]], dtype=np.float32)
result = cv2.perspectiveTransform(test_pt, H)
print(f'(50, 50) img → {result[0, 0]} campo')  # Debería ser ~(0, 0)
"
```

---

## 📋 Checklist de Diagnóstico

- [ ] Cámara conectada y publicando en `/roborescue/zenital/image_raw`
- [ ] Iluminación suficiente (ver ArUcos claramente en imagen cruda)
- [ ] ArUcos impresos son del tamaño correcto (8-10cm)
- [ ] Los 4 ArUcos de referencia (20, 21, 22, 23) son visibles
- [ ] IDs de ArUcos coinciden con código en `field_localizer.py`
- [ ] Distancia de cámara al campo es apropiada (80-120cm)
- [ ] Ángulo de cámara es perpendicular al campo
- [ ] Topic `/roborescue/robot_pose` está recibiendo datos
- [ ] Posiciones están dentro del rango esperado (0-300cm en X, 0-200cm en Y)

---

## 🔗 Referencias

- **Código principal:** `src/robot_localization/robot_localization/field_localizer.py`
- **Guía de uso:** `docs/guias/GUIA_ROBOT_LOCALIZATION.md`
- **OpenCV ArUco:** https://docs.opencv.org/4.x/d5/dae/tutorial_aruco_detection.html
- **Calibración de cámara:** https://docs.opencv.org/4.x/d4/d94/tutorial_camera_calibration.html

---

**Última actualización:** 2026-03-05  
**Equipo:** RoboRescue

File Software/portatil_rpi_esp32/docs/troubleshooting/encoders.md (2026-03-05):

# Troubleshooting - Encoders

## Todos los encoders muestran 0.0 RPM

### 2026-02-24: Alimentación o conexión incorrecta

**Síntoma:** Todos los encoders reportan 0.0 incluso cuando el robot se mueve

**Causas posibles:**
1. Alimentación de encoders no conectada (VCC y GND)
2. Cables A y B no conectados a GPIO correctos
3. micro-ROS agent no conectado
4. ROS_DOMAIN_ID incorrecto

**Checklist de verificación:**
- [ ] Alimentación de encoders: VCC → 3.3V/5V, GND → GND
- [ ] Cables A y B conectados según `docs/hardware/CONEXION_ENCODERS.md`
- [ ] Monitor serial ESP32 muestra "✅ Encoders configurados"
- [ ] micro-ROS agent conectado sin errores
- [ ] `export ROS_DOMAIN_ID=17` en todos los terminales

**Debug:**
```bash
# Verificar monitor serial
pio device monitor
# Debería mostrar: Encoders RPM -> FL:X.XX FR:X.XX ...

# Girar cada rueda manualmente (con motores desconectados)
# El valor de esa rueda específica debe cambiar
```

**Solución:**
1. Verificar conexiones físicas según guía
2. Asegurar que ROS_DOMAIN_ID=17 está configurado
3. Reiniciar ESP32 después de conectar agent

---

## Un encoder específico siempre 0.0

### 2026-02-24: Cable suelto o GPIO incorrecto

**Síntoma:** Un encoder reporta 0.0 mientras los demás funcionan

**Causas probables:**
1. Cable A o B suelto/roto
2. Alimentación del encoder (VCC/GND) mal conectada
3. GPIO incorrecto en el código

**Solución:**

1. **Verificar pines en código:**
   ```cpp
   // En esp32_roborescue/src/main.cpp
   #define ENCODER_FL_A 34
   #define ENCODER_FL_B 35
   #define ENCODER_FR_A 21
   #define ENCODER_FR_B 22
   #define ENCODER_RL_A 23
   #define ENCODER_RL_B 4
   #define ENCODER_RR_A 16
   #define ENCODER_RR_B 17
   ```

2. **Test rápido:**
   - Intercambiar temporalmente cables A/B de un encoder que funciona con el que no
   - Si el problema se mueve → cable/conector defectuoso
   - Si el problema persiste → conexión GPIO o encoder dañado

---

## Valores muy diferentes entre ruedas

### 2026-02-24: Fricción mecánica desigual

**Síntoma:** Durante avance recto, FL=50 RPM pero FR=10 RPM

**Causas:**
1. Fricción mecánica desigual (ruedas con más resistencia)
2. Motores desbalanceados (algunos más débiles)
3. Voltaje de batería bajo (PWM insuficiente)
4. Encoder mal calibrado (PPR incorrecto)

**Solución temporal:**
- Verificar que todas las ruedas giran libremente
- Cargar batería completamente
- Verificar que PPR en código es correcto (1496 counts/rev)

**Solución a futuro:**
- Implementar control PID individual por rueda
- Usar encoders para ajustar PWM y compensar diferencias

---

## Encoder cuenta en idle (robot detenido pero RPM ≠ 0)

### 2026-02-24: Ruido electromagnético

**Síntoma:** Encoder reporta valores aleatorios cuando robot está detenido

**Causas:**
1. **Ruido electromagnético:** Motores cercanos inducen señales falsas
2. **Cables muy largos:** Actúan como antenas
3. **Pull-ups insuficientes:** Señales flotando
4. **Vibración mecánica:** Robot vibra levemente

**Soluciones:**

1. **Añadir condensadores de desacoplamiento:**
   - 100nF (0.1µF) entre cada cable A/B y GND
   - Soldar lo más cerca posible del conector del encoder

2. **Separación física de cables:**
   - Mantener cables de encoders alejados de cables de potencia
   - Usar cable apantallado si es posible
   - Conectar malla a GND

3. **Añadir resistencias pull-up:**
   - Si encoders son open-collector: 10kΩ entre A/B y VCC

4. **Filtro por software:**
   - Ignorar valores < 5 RPM en el código

---

## RPM negativos cuando deberían ser positivos

### 2026-02-24: Cables A y B intercambiados

**Síntoma:** Encoder cuenta en dirección inversa (signo incorrecto)

**Causa:** Cables A y B intercambiados o motor girando en dirección opuesta

**Solución (recomendada):**
- Intercambiar físicamente cables A y B de ese encoder

**Solución alternativa:**
- Multiplicar por -1 en el código (`update_encoder_velocities()`)

---

## Topic /roborescue/encoder_velocities no aparece

### 2026-02-24: Paquetes ROS no compilados en ESP32

**Síntoma:** Agent conecta pero topic no existe

**Causas posibles:**
1. ESP32 no compilado con paquetes `std_msgs` y `geometry_msgs`
2. Namespace incorrecto en el código
3. Publisher no detectado por agent

**Solución:**
```bash
# Verificar que existe extra_packages.txt
cat esp32_roborescue/extra_packages.txt
# Debe contener: geometry_msgs y std_msgs

# Recompilar librerías
cd esp32_roborescue
pio run --target clean
pio run --target upload

# Reiniciar ESP32 (botón RST)
# Relanzar agent
export ROS_DOMAIN_ID=17
ros2 run micro_ros_agent micro_ros_agent serial --dev /dev/ttyUSB0 -b 115200
```

---

## Referencia Rápida - Encoders RoboRescue

**Especificaciones:**
- PPR motor: 11 pulsos/revolución
- Reducción: 1:34
- PPR rueda: 374 pulsos/vuelta
- Cuadratura (×4): 1496 counts/rev

**Pines asignados:**
| Motor | Canal A | Canal B |
|---|---|---|
| FL | GPIO 34 | GPIO 35 |
| FR | GPIO 21 | GPIO 22 |
| RL | GPIO 23 | GPIO 4  |
| RR | GPIO 16 | GPIO 17 |

**Última actualización:** 2026-02-24

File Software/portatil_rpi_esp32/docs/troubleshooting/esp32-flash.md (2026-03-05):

# Troubleshooting - ESP32

## Error "Failed to communicate with flash chip"

### 2026-02-24: GPIO 12 y 15 interfieren durante boot

**Síntoma:** No se puede subir código al ESP32 con robot conectado

**Causa:** GPIO 12 y 15 son sensibles durante boot del ESP32:
- **GPIO 12:** Controla voltaje de flash (3.3V vs 1.8V)
- **GPIO 15:** Habilita/deshabilita mensajes de debug durante boot

**Solución implementada:**
- Evitar GPIO 12 y 15 para encoders
- Usar GPIO 21, 22, 23 en su lugar (seguros durante boot)

**Si persiste el problema:**
1. Desconectar alimentación del robot (batería/fuente)
2. Mantener solo USB conectado
3. Subir código: `pio run --target upload`
4. Volver a conectar alimentación del robot

---

## Referencia Rápida - GPIOs ESP32

**❌ Evitar:**
- GPIO 0, 2, 15 (boot)
- GPIO 1, 3 (Serial)
- GPIO 6-11 (Flash)
- GPIO 12 (controla voltaje flash - evitar para encoders)
- GPIO 16, 17 (UART2 - problemas con motores)

**✅ Recomendados:**
- GPIO 18, 19, 21, 22, 23
- GPIO 25, 26, 27, 32, 33
- GPIO 4, 5, 13, 14
- GPIO 34, 35 (solo input - ideales para encoders)

**Última actualización:** 2026-02-24

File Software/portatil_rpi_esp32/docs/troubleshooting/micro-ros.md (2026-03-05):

# Troubleshooting - micro-ROS

## micro-ROS: "errno: 16 - Device busy"

### 2026-02-24: ROS_DOMAIN_ID no configurado

**Síntoma:** Agent no conecta, error "Device busy"

**Causa:** ROS_DOMAIN_ID no configurado o diferente entre ESP32 y RPI

**Solución:**
```bash
# Configurar en todos los terminales
export ROS_DOMAIN_ID=17

# Añadir permanentemente a ~/.bashrc (Laptop y RPI)
echo "export ROS_DOMAIN_ID=17" >> ~/.bashrc
source ~/.bashrc
```

**Verificar que está configurado:**
```bash
echo $ROS_DOMAIN_ID
# Debe mostrar: 17
```

---

## Agent conecta pero no hay comunicación

### 2026-02-24: ESP32 no responde después de conectar

**Síntoma:** Agent dice "connected" pero no aparecen topics del ESP32

**Solución:**
1. **Reiniciar ESP32:** Presionar botón RST físicamente
2. **Relanzar agent:**
   ```bash
   # Matar proceso anterior si existe
   pkill -9 micro_ros_agent
   
   # Lanzar nuevamente
   export ROS_DOMAIN_ID=17
   ros2 run micro_ros_agent micro_ros_agent serial --dev /dev/ttyUSB0 -b 115200
   ```

3. **Verificar topics:**
   ```bash
   ros2 topic list | grep roborescue
   # Debería aparecer: /roborescue/cmd_vel, /roborescue/encoder_velocities
   ```

---

## Puerto serial no encontrado (/dev/ttyUSB0)

### 2026-02-24: ESP32 no detectado por sistema

**Síntoma:** Error "No such file or directory: /dev/ttyUSB0"

**Solución:**

1. **Verificar qué puerto usa el ESP32:**
   ```bash
   ls /dev/ttyUSB* /dev/ttyACM*
   # Puede ser: /dev/ttyUSB0, /dev/ttyUSB1, /dev/ttyACM0, etc.
   ```

2. **Dar permisos al usuario:**
   ```bash
   sudo usermod -a -G dialout $USER
   # Logout y login para aplicar cambios
   ```

3. **Lanzar agent con puerto correcto:**
   ```bash
   ros2 run micro_ros_agent micro_ros_agent serial --dev /dev/ttyUSB1 -b 115200
   ```

---

**Última actualización:** 2026-02-24

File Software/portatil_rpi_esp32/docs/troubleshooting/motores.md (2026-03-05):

# Troubleshooting - Motores (Robot Casa - L298N)

## Motor no retrocede

### 2026-02-07: GPIO 16/17 son UART2

**Síntoma:** Motor avanza pero no retrocede (zumba sin moverse)

**Causa:** GPIO 16/17 son pines UART2 (RX2/TX2) con restricciones hardware

**Solución:** Cambio de pines
```cpp
// ANTES
#define M3_IN3 16 // RX2
#define M3_IN4 17 // TX2

// DESPUÉS
#define M3_IN3 18 // GPIO propósito general
#define M3_IN4 19 // GPIO propósito general
```

**Resultado:** ✅ Motor funciona en ambas direcciones. GPIOs 18/19 libres de restricciones.

**Acción:** Reconectar cables + recompilar firmware

---

## Motores zumban pero no se mueven (L298N)

### 2026-02-07: PWM insuficiente por caída de voltaje

**Síntoma:** Con velocidad 0.3 motores zumban pero no se mueven

**Causa:** L298N tiene caída de voltaje ~2V. PWM bajo no genera torque suficiente.

**Solución:** Usar velocidades mínimas 0.8-1.0 (80-100%)

**Resultado:** ✅ Movimiento correcto con velocidades altas

---

## Referencia - Drivers de Motores

**L298N:** 
- Requiere velocidades >0.8 (80%)
- Caída de voltaje ~2V
- Mejor para robots grandes con baterías de alto voltaje

**DFRobot:** 
- Funciona con velocidades >0.3 (30%)
- Menor caída de voltaje
- Mejor para robots pequeños

**Última actualización:** 2026-02-24

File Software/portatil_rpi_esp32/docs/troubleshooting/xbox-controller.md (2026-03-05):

# Troubleshooting - Xbox Controller

## 🎮 Problemas Comunes del Xbox Controller

Este documento cubre problemas específicos del control del robot mediante Xbox Controller.

**Componente:** `xbox_controler/xbox_teleop.py`  
**Referencias:** Ver `docs/guias/GUIA_XBOX_CONTROLLER.md`

---

## ❌ Joystick No Es Detectado

### Síntomas
```
Error: No joystick device found
ls /dev/input/js* returns nothing
jstest-gtk shows "No devices"
```

### Causas y Soluciones

#### 1. **Joystick No Conectado**

**Verificación:**
```bash
# Ver dispositivos USB
lsusb | grep -i joy
lsusb | grep -i "microsoft\|xbox"

# Verificar que aparece en /dev/input/
ls -la /dev/input/js*  # Debería mostrar js0, js1, etc.
```

**Solución:**
- Desconecta y vuelve a conectar el joystick
- Intenta otro puerto USB
- Prueba el joystick en otra computadora para verificar que funciona

---

#### 2. **Permisos Insuficientes**

**Error típico:**
```
Permission denied: /dev/input/js0
```

**Soluciones rápidas:**

```bash
# Opción A: Cambiar permisos temporalmente (pierde efecto en reinicio)
sudo chmod 666 /dev/input/js*

# Opción B: Agregar usuario al grupo dialout (permanente)
sudo usermod -a -G input $USER
# Requiere logout/login para aplicarse

# Verificar que funciona:
jstest /dev/input/js0
```

---

#### 3. **Controlador joy_node No Instalado**

**Verificación:**
```bash
ros2 pkg list | grep joy
# Debería mostrar: joy
```

**Instalación:**
```bash
# Ubuntu/Debian
sudo apt install -y ros-humble-joy

# Luego reinicia/recompila
source /opt/ros/humble/setup.bash
```

---

## 🔕 Joystick Detectado pero Robot No Responde

### Síntomas
- Joystick funciona en otras apps
- `jstest` muestra movimientos del stick
- Pero `/roborescue/cmd_vel` no recibe comandos

### Causas y Soluciones

#### 1. **joy_node No Está Corriendo**

**Verificación:**
```bash
# Ver nodos activos
ros2 node list | grep joy

# Si no aparece, iniciar manualmente:
ros2 run joy joy_node --ros-args -p dev:=/dev/input/js0
```

**Solución automática (agregar a startup):**
```bash
# Crear script de inicio: ~/.bashrc o similar
alias joy_start='ros2 run joy joy_node --ros-args -p dev:=/dev/input/js0'
```

---

#### 2. **xbox_teleop No Está Corriendo**

**Verificación:**
```bash
# Ver nodos activos
ros2 node list | grep xbox

# Si no aparece, iniciar:
ros2 run xbox_controler xbox_teleop
```

**Troubleshooting si da error:**
```bash
# Verificar que el paquete está compilado
colcon build --packages-select xbox_controler
source install/setup.bash

# Luego intentar de nuevo
ros2 run xbox_controler xbox_teleop
```

---

#### 3. **Namespace Incorrecto**

**Problema:** El nodo publica a `/roborescue/cmd_vel` pero el robot espera en otro topic

**Verificación:**
```bash
# Ver a dónde publica el xbox_teleop
ros2 topic info /roborescue/cmd_vel
# Debería mostrar "Type: geometry_msgs/msg/Twist"

# Ver suscriptores
ros2 topic list | grep cmd_vel
# Debería haber un suscriptor en el robot
```

**Solución:**
```bash
# Si necesitas cambiar el topic de destino:
ros2 run xbox_controler xbox_teleop \
    -p cmd_vel_topic:=/roborescue/cmd_vel_custom
```

---

#### 4. **Botón de Seguridad (RB) No Está Presionado**

**Síntoma:**
- El joystick mueve pero el robot no se mueve
- Suelta RB y el robot se detiene

**Solución:**
- Mantén presionado RB (botón 5) mientras mueves los sticks
- Si RB está roto, cambiar el botón de seguridad:

```bash
# Usar botón Y (botón 3) como seguridad
ros2 run xbox_controler xbox_teleop \
    -p enable_button:=3
```

---

## 🔀 Controles Invertidos o Incorrectos

### Síntomas
- Adelante hace retroceder
- Giro es al revés
- Sticks no responden como se espera

### Causas y Soluciones

#### 1. **Ejes Mapeados Incorrectamente**

**Primero, verificar qué ejes corresponden:**
```bash
# Iniciar jstest
jstest /dev/input/js0

# Mover sticks y tomar nota:
# - Stick izquierdo arriba/abajo → observar qué eje cambia
# - Stick izquierdo izq/der → observar qué eje cambia
# - Stick derecho izq/der → observar qué eje cambia
```

**Mapeo estándar Xbox 360/One:**

| Movimiento | Eje | Rango |
|---|-----|---|
| Stick Izq. Arriba/Abajo | Eje 1 | -1.0 a 1.0 |
| Stick Izq. Izq/Der | Eje 0 | -1.0 a 1.0 |
| Stick Der. Izq/Der | Eje 3 | -1.0 a 1.0 |
| Stick Der. Arriba/Abajo | Eje 4 | -1.0 a 1.0 |
| LT (Gatillo izq.) | Eje 2 | -1.0 a 1.0 |
| RT (Gatillo der.) | Eje 5 | -1.0 a 1.0 |

**Solución (reconfigurar ejes):**
```bash
# Si tu joystick tiene ejes diferentes:
ros2 run xbox_controler xbox_teleop \
    -p axis_linear_x:=1 \
    -p axis_linear_y:=0 \
    -p axis_angular_yaw:=3
```

---

#### 2. **Direcciones Invertidas (Escalas Negativas)**

**Síntomas:**
- Adelante hace retroceder
- Giro es opuesto
- Strafe es al revés

**Solución (invertir direcciones):**
```bash
# Invertir adelante/atrás:
ros2 run xbox_controler xbox_teleop \
    -p scale_linear_x:=-1.0

# Invertir strafe:
ros2 run xbox_controler xbox_teleop \
    -p scale_linear_y:=1.0  # Cambiar de -1.0 a 1.0

# Invertir giro:
ros2 run xbox_controler xbox_teleop \
    -p scale_angular_yaw:=1.0  # Cambiar de -1.0 a 1.0
```

---

#### 3. **Velocidad Muy Alta/Baja**

**Síntomas:**
- Robot es demasiado sensible (se mueve rápido)
- Robot es muy lento
- Movimientos no son suave

**Soluciones:**

Reducir velocidad:
```bash
ros2 run xbox_controler xbox_teleop \
    -p scale_linear_x:=0.5 \
    -p scale_linear_y:=0.5 \
    -p scale_angular_yaw:=0.3
```

Aumentar velocidad:
```bash
ros2 run xbox_controler xbox_teleop \
    -p scale_linear_x:=1.0 \
    -p scale_linear_y:=1.0 \
    -p scale_angular_yaw:=0.8
```

**Valores recomendados por caso:**

| Caso | scale_linear_x | scale_angular_yaw | Notas |
|---|---|---|---|
| Muy sensible | 0.3-0.5 | 0.2-0.3 | Para espacios reducidos |
| Normal (recomendado) | 0.8-1.0 | 0.5-0.7 | Para competencia |
| Precisión (lento) | 0.2-0.3 | 0.1-0.2 | Para pruebas delicadas |
| Máxima velocidad | 1.0 | 1.0 | Riesgo: puede ser incontrolable |

---

## 📊 Verificación de Funcionamiento

### Test 1: Verificar que joy_node publica

```bash
# Terminal 1: Iniciar joy_node
ros2 run joy joy_node

# Terminal 2: Ver datos del joystick
ros2 topic echo /joy

# Resultado esperado: ver cambios en axes y buttons al mover el control
```

---

### Test 2: Verificar que xbox_teleop procesa inputs

```bash
# Terminal 1: Iniciar joy_node
ros2 run joy joy_node

# Terminal 2: Iniciar xbox_teleop
ros2 run xbox_controler xbox_teleop

# Terminal 3: Monitorear salida
ros2 topic echo /roborescue/cmd_vel

# Resultado esperado:
# - Mover stick izq. arriba → linear.x cambia
# - Mover stick izq. izq → linear.y cambia
# - Mover stick der. izq/der → angular.z cambia
```

---

### Test 3: Verificar que robot recibe comandos

```bash
# Terminal 1: Iniciar joy_node y xbox_teleop (como arriba)

# Terminal 2: Ver información del topic
ros2 topic info /roborescue/cmd_vel

# Resultado esperado:
# "Publishers: 1"  (xbox_teleop)
# "Subscribers: 1" (robot)

# Si hay 0 suscriptores, el robot no está escuchando
```

---

## 🔌 Joystick Desconectado/Reconectado

### Síntoma
Después de desconectar y reconectar el joystick, los comandos no funcionan

### Solución

```bash
# 1. Detener joy_node
ros2 node kill /joy_node

# 2. Esperar 2 segundos

# 3. Reconectar joystick USB

# 4. Reiniciar joy_node
ros2 run joy joy_node

# 5. Verificar que está activo
ros2 node list | grep joy
```

---

## ⚡ Comportamiento Errático (Movimientos Aleatorios)

### Síntomas
- Robot se mueve sin que toque el joystick
- Movimientos inconsistentes
- ROS_DOMAIN_ID conflictivo

### Causas y Soluciones

#### 1. **Interferencia con Otro ROS2 (Domain ID Conflict)**

**Verificación:**
```bash
# Ver ROS_DOMAIN_ID actual
echo $ROS_DOMAIN_ID

# Debería ser: 17
```

**Solución:**
```bash
# En laptop:
export ROS_DOMAIN_ID=17

# En RPI:
export ROS_DOMAIN_ID=17

# Añadir a ~/.bashrc para persistencia:
echo "export ROS_DOMAIN_ID=17" >> ~/.bashrc
source ~/.bashrc
```

---

#### 2. **Múltiples Instancias de xbox_teleop**

**Verificación:**
```bash
# Ver cuántos nodos xbox_teleop hay
ros2 node list | grep xbox

# Si hay más de 1, hay conflicto
```

**Solución:**
```bash
# Matar todas las instancias
pkill -f xbox_teleop

# Iniciar una sola:
ros2 run xbox_controler xbox_teleop
```

---

#### 3. **Joystick Defectuoso (Drift)**

**Síntomas:**
- Sin mover el stick, los ejes varían
- Valor "reposo" no es cero (0.1-0.5)

**Verificación:**
```bash
# Sin tocar el joystick:
jstest /dev/input/js0

# Observar los ejes, todos deberían estar en 0.00
```

**Soluciones:**
1. Calibrar joystick (si el SO proporciona herramienta)
2. Aumentar "dead zone" en código (ignorar pequeños valores):

```python
# Agregar en xbox_teleop.py después de leer los ejes:
DEADZONE = 0.1

if abs(cmd.linear.x) < DEADZONE:
    cmd.linear.x = 0.0
if abs(cmd.linear.y) < DEADZONE:
    cmd.linear.y = 0.0
if abs(cmd.angular.z) < DEADZONE:
    cmd.angular.z = 0.0
```

3. Si no funciona, el joystick puede estar defectuoso → reemplazar

---

## 🖥️ Comandos Útiles para Diagnóstico

```bash
# Lista de comandos útiles para debugging

# 1. Ver dispositivos de entrada disponibles
lsusb | grep -i joy
ls /dev/input/

# 2. Probar joystick directamente
jstest /dev/input/js0
jstest-gtk

# 3. Ver nodos activos
ros2 node list

# 4. Ver topics disponibles
ros2 topic list

# 5. Verificar suscriptor de cmd_vel
ros2 topic info /roborescue/cmd_vel

# 6. Monitorear inputs del joystick
ros2 topic echo /joy

# 7. Monitorear comandos enviados
ros2 topic echo /roborescue/cmd_vel

# 8. Matar nodo específico
ros2 node kill /xbox_teleop
ros2 node kill /joy_node

# 9. Elevar verbosidad de logs
ros2 run xbox_controler xbox_teleop --ros-args --log-level DEBUG

# 10. Ver parámetros del nodo
ros2 param list /xbox_teleop
ros2 param get /xbox_teleop scale_linear_x
```

---

## 📋 Checklist de Diagnóstico

- [ ] Joystick conectado (`lsusb` muestra device)
- [ ] Archivo de dispositivo existe (`/dev/input/js0`)
- [ ] Permisos suficientes (sin "Permission denied")
- [ ] `joy_node` está corriendo (`ros2 node list`)
- [ ] `/joy` topic tiene datos (`ros2 topic echo /joy`)
- [ ] `xbox_teleop` está corriendo
- [ ] `/roborescue/cmd_vel` recibe datos
- [ ] Robot está suscrito a `/roborescue/cmd_vel`
- [ ] ROS_DOMAIN_ID=17 está configurado
- [ ] Botón RB funciona (presionado → robot responde)
- [ ] Joystick no tiene drift (test en `jstest`)

---

## 🔗 Referencias

- **Código principal:** `src/xbox_controler/xbox_controler/xbox_teleop.py`
- **Guía de uso:** `docs/guias/GUIA_XBOX_CONTROLLER.md`
- **ROS2 Joy:** https://github.com/ros-drivers/joystick_drivers
- **Documentación Joy:** https://docs.ros.org/en/humble/p/joy/

---

**Última actualización:** 2026-03-05  
**Equipo:** RoboRescue

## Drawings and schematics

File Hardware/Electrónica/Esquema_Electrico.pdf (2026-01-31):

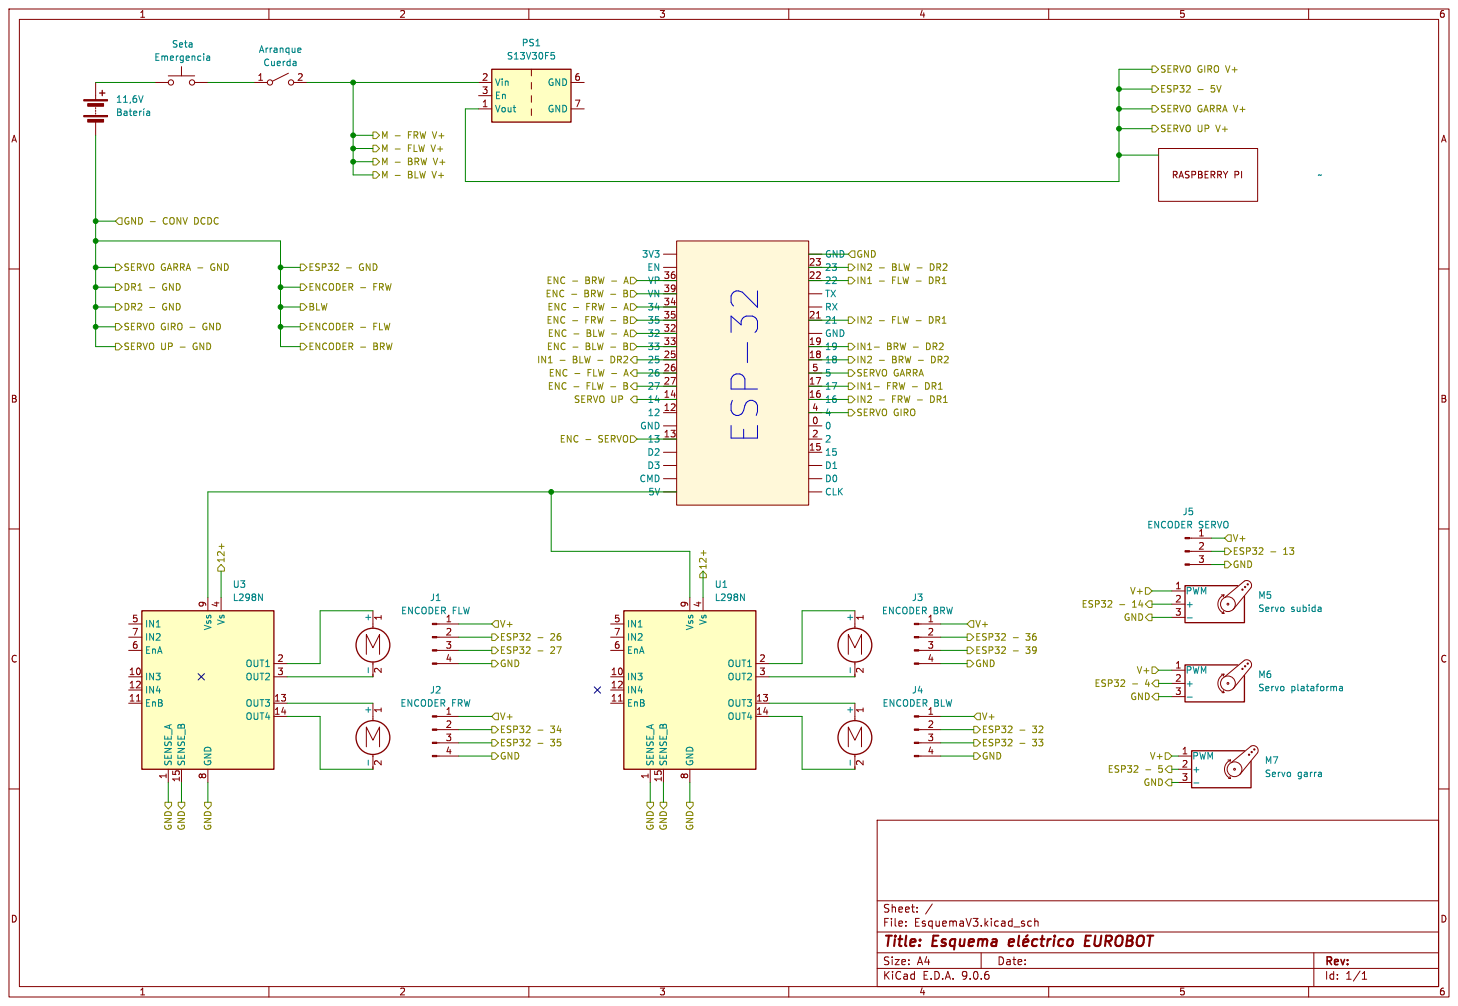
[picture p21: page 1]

SERVO UP - GND GND

SERVO UP V+ SERVO GARRA V+ SERVO GIRO V+ ESP-32

DR2 - GND GND - CONV DCDC

File: EsquemaV3.kicad_sch Sheet: /
Id: 1/1 Title: Esquema þÿeléctrico EUROBOT

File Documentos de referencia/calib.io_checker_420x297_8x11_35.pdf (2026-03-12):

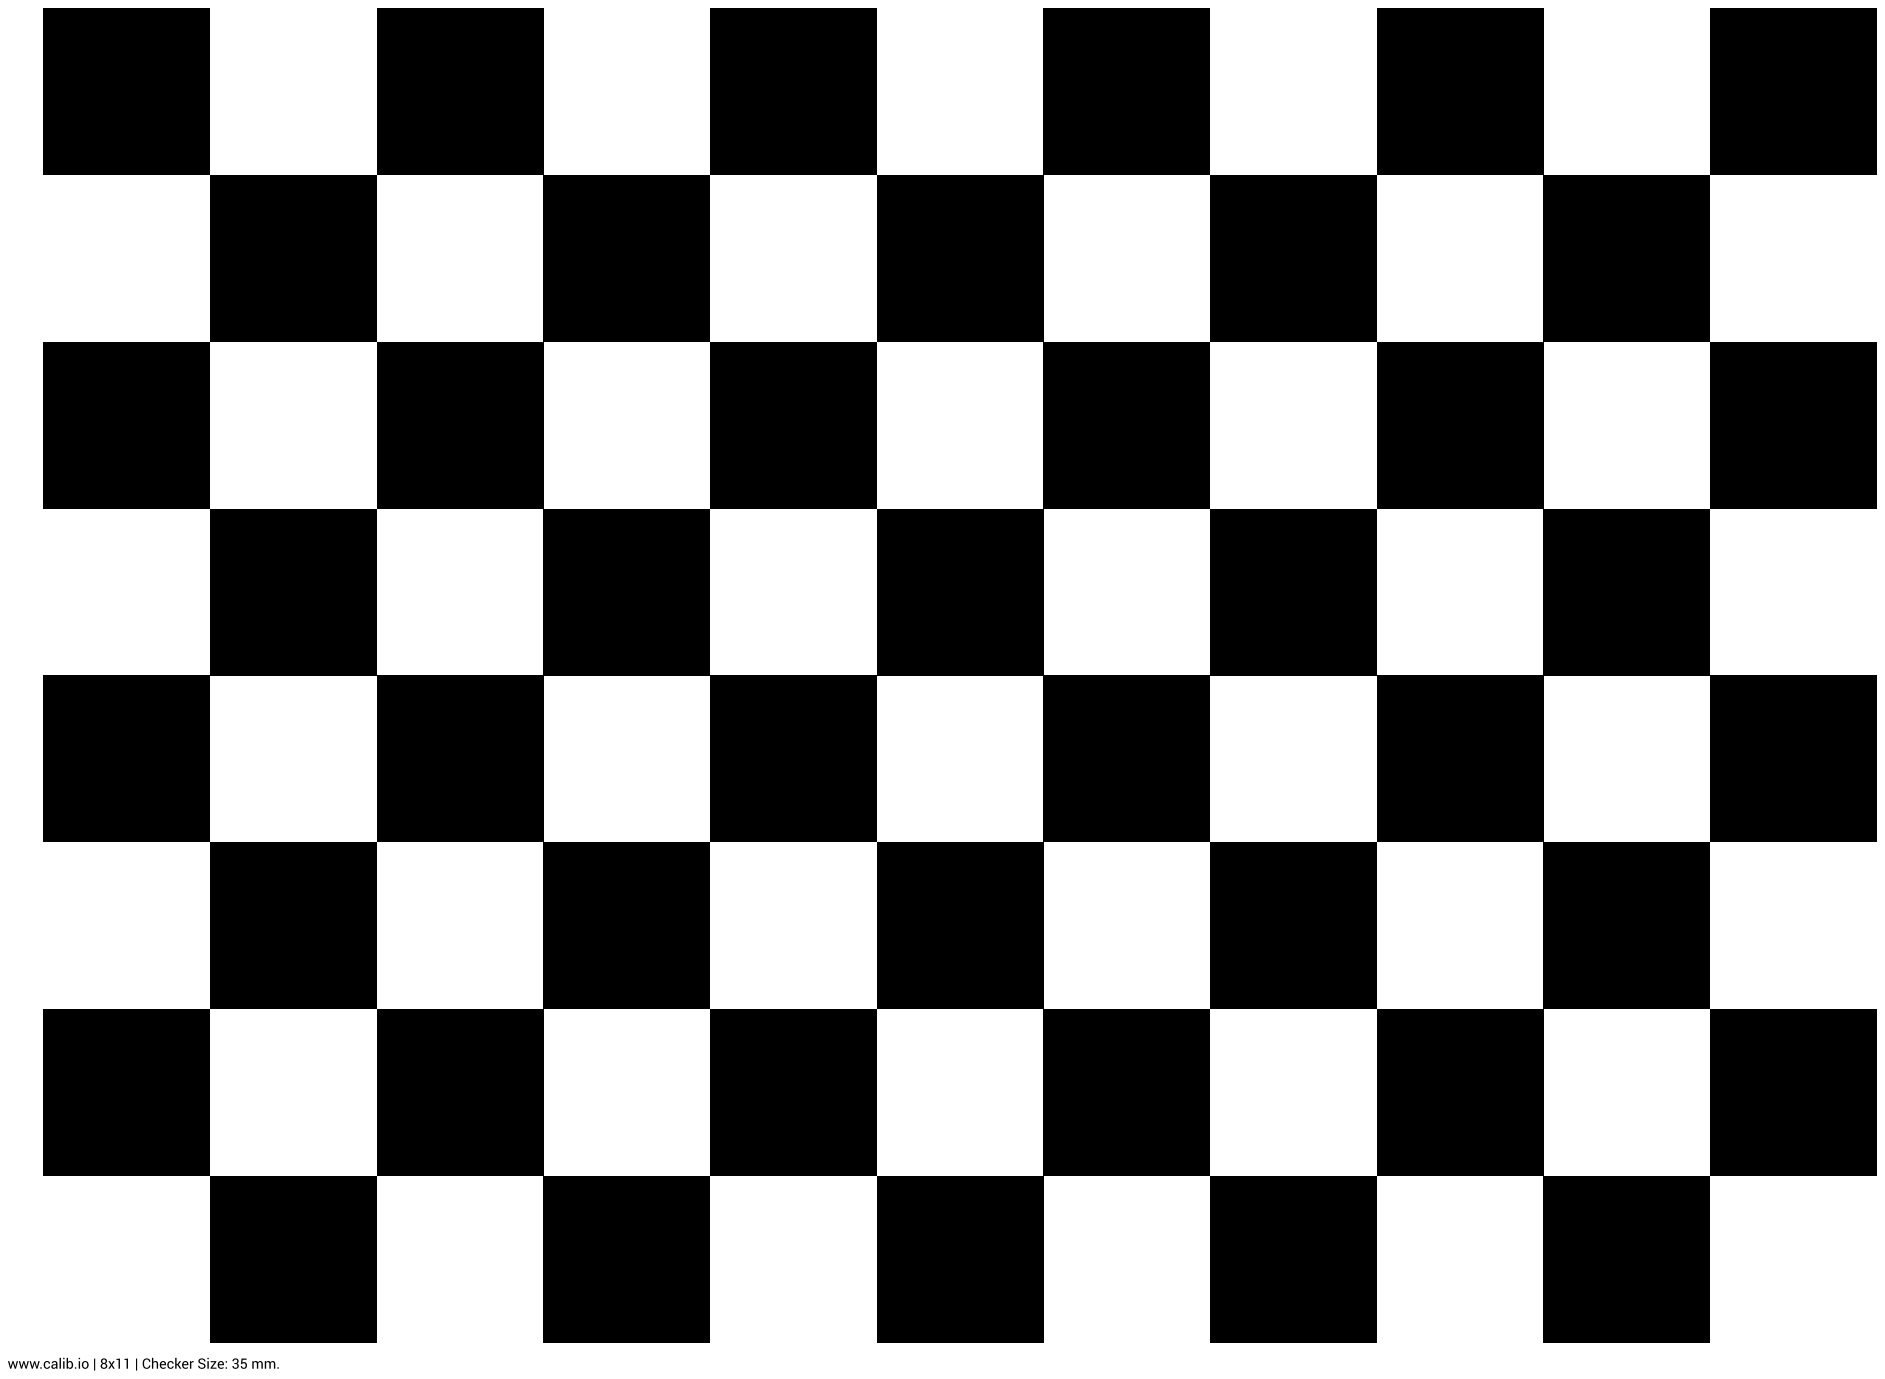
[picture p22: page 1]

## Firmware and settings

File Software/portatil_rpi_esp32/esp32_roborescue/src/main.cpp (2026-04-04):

#include <Arduino.h>
#include <micro_ros_arduino.h>
#include <rcl/rcl.h>
#include <rclc/rclc.h>
#include <rclc/executor.h>
#include <geometry_msgs/msg/twist.h>
#include <std_msgs/msg/float32_multi_array.h>

portMUX_TYPE mux = portMUX_INITIALIZER_UNLOCKED;

// ================================================================
//  ZONA DE CONFIGURACIÓN DEL CHASIS Y CINEMÁTICA
// ================================================================

// Parámetros PID individuales por motor (Overshoot=1.5%, ts=0.52s)
const float Kp_FL = 218.9; const float Ki_FL = 1488.0;
const float Kp_FR = 129.4; const float Ki_FR = 1130.0;
const float Kp_RL = 200.8; const float Ki_RL = 1435.0;
const float Kp_RR = 159.7; const float Ki_RR = 1078.0;

// Compensación de fricción
const int base_FL = 89; const int base_FR = 47;
const int base_RL = 84; const int base_RR = 78;

// Geometría del robot (en metros)
const float LX = 0.130;  
const float LY = 0.075;  
const float K_GEOMETRIA = LX + LY; // 0.205

// ================================================================
//  PINES Y CONFIGURACIÓN HARDWARE
// ================================================================
#define FL_PWM 13    
#define FL_DIR 25  
#define FR_PWM 33   
#define FR_DIR 32  
#define RL_PWM 18
#define RL_DIR 4
#define RR_PWM 21
#define RR_DIR 19

#define FL_ENC_A 16
#define FL_ENC_B 17
#define FR_ENC_A 26
#define FR_ENC_B 27
#define RL_ENC_A 22
#define RL_ENC_B 23
#define RR_ENC_A 34
#define RR_ENC_B 35

// Canales PWM clásicos (v2.x)
const int ch_FL = 0;
const int ch_FR = 1;
const int ch_RL = 2;
const int ch_RR = 3;

const int freq = 1000;
const int resolution = 8;
const float RADIO_RUEDA = 0.0325; 
const int COUNTS_PER_REV = (11 * 34) * 4; 
const float rads_por_cuenta = (2.0f * PI) / (float)COUNTS_PER_REV;
const unsigned long ventana_us = 40000; // 40ms control loop

// ================================================================
//  VARIABLES DE ESTADO (PID y Encoders)
// ================================================================
volatile long cont_FL = 0, cont_FR = 0, cont_RL = 0, cont_RR = 0;
long prev_FL = 0, prev_FR = 0, prev_RL = 0, prev_RR = 0;
unsigned long lastWindowUs = 0;
double errSum_FL = 0, errSum_FR = 0, errSum_RL = 0, errSum_RR = 0;

// Referencias calculadas por la cinemática para cada rueda
float ref_FL = 0.0, ref_FR = 0.0, ref_RL = 0.0, ref_RR = 0.0;

// Comandos globales recibidos de la Raspberry
float comando_Vx = 0.0;
float comando_Vy = 0.0;
float comando_W  = 0.0;

// ================================================================
//  VARIABLES MICRO-ROS
// ================================================================
rcl_subscription_t subscriber;
rcl_publisher_t publisher_encoder_vel;
geometry_msgs__msg__Twist msg;
std_msgs__msg__Float32MultiArray encoder_msg;
rclc_executor_t executor;
rclc_support_t support;
rcl_allocator_t allocator;
rcl_node_t node;
rcl_init_options_t init_options;

unsigned long last_msg_time = 0;

// ================================================================
//  INTERRUPCIONES DE ENCODERS
// ================================================================
void IRAM_ATTR isr_FL_A() { (digitalRead(FL_ENC_A) != digitalRead(FL_ENC_B)) ? cont_FL-- : cont_FL++; }
void IRAM_ATTR isr_FR_A() { (digitalRead(FR_ENC_A) != digitalRead(FR_ENC_B)) ? cont_FR-- : cont_FR++; }
void IRAM_ATTR isr_RL_A() { (digitalRead(RL_ENC_A) != digitalRead(RL_ENC_B)) ? cont_RL-- : cont_RL++; }
void IRAM_ATTR isr_RR_A() { (digitalRead(RR_ENC_A) != digitalRead(RR_ENC_B)) ? cont_RR-- : cont_RR++; }
void IRAM_ATTR isr_FL_B() { (digitalRead(FL_ENC_A) == digitalRead(FL_ENC_B)) ? cont_FL-- : cont_FL++; }
void IRAM_ATTR isr_FR_B() { (digitalRead(FR_ENC_A) == digitalRead(FR_ENC_B)) ? cont_FR-- : cont_FR++; }
void IRAM_ATTR isr_RL_B() { (digitalRead(RL_ENC_A) == digitalRead(RL_ENC_B)) ? cont_RL-- : cont_RL++; }
void IRAM_ATTR isr_RR_B() { (digitalRead(RR_ENC_A) == digitalRead(RR_ENC_B)) ? cont_RR-- : cont_RR++; }

// ================================================================
//  CALLBACK MICRO-ROS (La Oreja del Robot)
// ================================================================
void subscription_callback(const void * msgin) {
  const geometry_msgs__msg__Twist * msg = (const geometry_msgs__msg__Twist *)msgin;
  last_msg_time = millis(); // Reseteamos el perro guardián
  
  // Guardamos las velocidades ordenadas por la Raspberry
  comando_Vx = msg->linear.x;
  comando_Vy = msg->linear.y;
  comando_W  = msg->angular.z;
}

// ================================================================
//  FUNCIÓN DE CINEMÁTICA MECANUM
// ================================================================
void calcular_cinematica(float Vx, float Vy, float W) {
  ref_FL = Vx + Vy - (W * K_GEOMETRIA);
  ref_FR = Vx - Vy + (W * K_GEOMETRIA);
  ref_RL = Vx - Vy - (W * K_GEOMETRIA);
  ref_RR = Vx + Vy + (W * K_GEOMETRIA);
}

// ================================================================
//  FUNCIÓN PID BIDIRECCIONAL
// ================================================================
int calcular_pwm_rueda(float v_deseada, float v_actual, double &memoria_integral, int pwm_base_motor, float kp, float ki) {
  if (v_deseada == 0.0) { memoria_integral = 0; return 0; }
  double dt = (double)ventana_us / 1000000.0;
  double error = v_deseada - v_actual;
  memoria_integral += (error * dt);

  double limite_integral = (255.0 - pwm_base_motor) / ki; 
  if (memoria_integral > limite_integral) memoria_integral = limite_integral;
  else if (memoria_integral < -limite_integral) memoria_integral = -limite_integral;

  double Output = (kp * error) + (ki * memoria_integral);
  int pwm_final = 0;
  
  if (v_deseada > 0.0) {
    if (Output > 0) pwm_final = pwm_base_motor + (int)Output;
    else pwm_final = 0; 
  } else if (v_deseada < 0.0) {
    if (Output < 0) pwm_final = -(pwm_base_motor + (int)abs(Output));
    else pwm_final = 0; 
  }

  if (pwm_final > 255) pwm_final = 255;
  if (pwm_final < -255) pwm_final = -255;
  return pwm_final;
}

// ================================================================
//  SETUP
// ================================================================
void setup() {
  // 1. Configurar Hardware Motores
  pinMode(FL_DIR, OUTPUT); pinMode(RL_DIR, OUTPUT);
  pinMode(FR_DIR, OUTPUT); pinMode(RR_DIR, OUTPUT);
  
  // Sintaxis clásica para PWM
  ledcSetup(ch_FL, freq, resolution); ledcAttachPin(FL_PWM, ch_FL);
  ledcSetup(ch_FR, freq, resolution); ledcAttachPin(FR_PWM, ch_FR);
  ledcSetup(ch_RL, freq, resolution); ledcAttachPin(RL_PWM, ch_RL);
  ledcSetup(ch_RR, freq, resolution); ledcAttachPin(RR_PWM, ch_RR);

  // Asegurar PWM a 0 en el arranque
  ledcWrite(ch_FL, 0); ledcWrite(ch_FR, 0);
  ledcWrite(ch_RL, 0); ledcWrite(ch_RR, 0);

  // 2. Configurar Encoders
  pinMode(FL_ENC_A, INPUT_PULLUP); pinMode(FL_ENC_B, INPUT_PULLUP);
  pinMode(FR_ENC_A, INPUT_PULLUP); pinMode(FR_ENC_B, INPUT_PULLUP);
  pinMode(RL_ENC_A, INPUT_PULLUP); pinMode(RL_ENC_B, INPUT_PULLUP);
  pinMode(RR_ENC_A, INPUT_PULLUP); pinMode(RR_ENC_B, INPUT_PULLUP);

  attachInterrupt(digitalPinToInterrupt(FL_ENC_A), isr_FL_A, CHANGE);
  attachInterrupt(digitalPinToInterrupt(FL_ENC_B), isr_FL_B, CHANGE);
  attachInterrupt(digitalPinToInterrupt(FR_ENC_A), isr_FR_A, CHANGE);
  attachInterrupt(digitalPinToInterrupt(FR_ENC_B), isr_FR_B, CHANGE);
  attachInterrupt(digitalPinToInterrupt(RL_ENC_A), isr_RL_A, CHANGE);
  attachInterrupt(digitalPinToInterrupt(RL_ENC_B), isr_RL_B, CHANGE);
  attachInterrupt(digitalPinToInterrupt(RR_ENC_A), isr_RR_A, CHANGE);
  attachInterrupt(digitalPinToInterrupt(RR_ENC_B), isr_RR_B, CHANGE);

  // 3. Configurar Micro-ROS
  Serial.begin(115200);
  set_microros_transports();
  
  allocator = rcl_get_default_allocator();
  init_options = rcl_get_zero_initialized_init_options();
  rcl_init_options_init(&init_options, allocator);
  rcl_init_options_set_domain_id(&init_options, 17);
  
  rclc_support_init_with_options(&support, 0, NULL, &init_options, &allocator);
  rclc_node_init_default(&node, "esp32_mecanum", "roborescue", &support);
  
  // Suscriptor de Comandos
  rclc_subscription_init_default(
    &subscriber, &node,
    ROSIDL_GET_MSG_TYPE_SUPPORT(geometry_msgs, msg, Twist),
    "cmd_vel");
  
  // Publicador de Odometría (4 floats: vel m/s de cada rueda)
  encoder_msg.data.capacity = 4;
  encoder_msg.data.size = 4;
  encoder_msg.data.data = (float*) malloc(encoder_msg.data.capacity * sizeof(float));
  
  rclc_publisher_init_default(
    &publisher_encoder_vel, &node,
    ROSIDL_GET_MSG_TYPE_SUPPORT(std_msgs, msg, Float32MultiArray),
    "encoder_velocities");
      
  rclc_executor_init(&executor, &support.context, 1, &allocator);
  rclc_executor_add_subscription(&executor, &subscriber, &msg, &subscription_callback, ON_NEW_DATA);
  
  lastWindowUs = micros();
  last_msg_time = millis();
}

// ================================================================
//  LOOP MAESTRO
// ================================================================
void loop() {
  // 1. Escuchar a la Raspberry Pi
  rclc_executor_spin_some(&executor, RCL_MS_TO_NS(10));

  // 2. Perro Guardián (Si falla la conexión por > 500ms, frenar)
  if (millis() - last_msg_time > 500) {
    comando_Vx = 0.0;
    comando_Vy = 0.0;
    comando_W  = 0.0;
  }

  // 3. Bucle de Control a 40ms
  unsigned long ahora_us = micros();
  if ((ahora_us - lastWindowUs) >= ventana_us) {
    unsigned long ventana_real_us = ahora_us - lastWindowUs;
    lastWindowUs = ahora_us;

    // A. Traducir comando a velocidades de rueda
    calcular_cinematica(comando_Vx, comando_Vy, comando_W);

    // B. Leer Encoders de forma segura
    portENTER_CRITICAL(&mux);
    long current_FL = cont_FL; long current_FR = cont_FR;
    long current_RL = cont_RL; long current_RR = cont_RR;
    portEXIT_CRITICAL(&mux);

    long delta_FL = current_FL - prev_FL; long delta_FR = current_FR - prev_FR;
    long delta_RL = current_RL - prev_RL; long delta_RR = current_RR - prev_RR;

    prev_FL = current_FL; prev_FR = current_FR;
    prev_RL = current_RL; prev_RR = current_RR;

    // C. Calcular velocidades actuales en m/s
    float rads_FL = -(((float)delta_FL * 1000000.0f) / (float)ventana_real_us) * rads_por_cuenta;
    float rads_FR = (((float)delta_FR * 1000000.0f) / (float)ventana_real_us) * rads_por_cuenta;
    float rads_RL = -(((float)delta_RL * 1000000.0f) / (float)ventana_real_us) * rads_por_cuenta;
    float rads_RR = (((float)delta_RR * 1000000.0f) / (float)ventana_real_us) * rads_por_cuenta;

    float v_FL = rads_FL * RADIO_RUEDA; float v_FR = rads_FR * RADIO_RUEDA;
    float v_RL = rads_RL * RADIO_RUEDA; float v_RR = rads_RR * RADIO_RUEDA;

    // D. Calcular PIDs
    int pwm_FL = calcular_pwm_rueda(ref_FL, v_FL, errSum_FL, base_FL, Kp_FL, Ki_FL);
    int pwm_FR = calcular_pwm_rueda(ref_FR, v_FR, errSum_FR, base_FR, Kp_FR, Ki_FR);
    int pwm_RL = calcular_pwm_rueda(ref_RL, v_RL, errSum_RL, base_RL, Kp_RL, Ki_RL);
    int pwm_RR = calcular_pwm_rueda(ref_RR, v_RR, errSum_RR, base_RR, Kp_RR, Ki_RR);

    // E. Mover hardware (usando la sintaxis clásica de canales)
    digitalWrite(FL_DIR, (pwm_FL >= 0) ? LOW : HIGH); ledcWrite(ch_FL, abs(pwm_FL));
    digitalWrite(FR_DIR, (pwm_FR >= 0) ? HIGH : LOW); ledcWrite(ch_FR, abs(pwm_FR));
    digitalWrite(RL_DIR, (pwm_RL >= 0) ? LOW : HIGH); ledcWrite(ch_RL, abs(pwm_RL));
    digitalWrite(RR_DIR, (pwm_RR >= 0) ? HIGH : LOW); ledcWrite(ch_RR, abs(pwm_RR));

    // F. Informar a la Raspberry Pi
    encoder_msg.data.data[0] = v_FL;
    encoder_msg.data.data[1] = v_FR;
    encoder_msg.data.data[2] = v_RL;
    encoder_msg.data.data[3] = v_RR;
    rcl_publish(&publisher_encoder_vel, &encoder_msg, NULL);
  }
}

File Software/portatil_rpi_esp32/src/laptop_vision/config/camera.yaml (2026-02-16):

# Configuración de Cámara para el paquete laptop_vision

camera_publisher:
  ros__parameters:
    video_url: "http://192.168.100.122:5000/video"  # Cámara IP (móvil con app IPCamera)
    namespace: "roborescue"
    publish_rate: 10.0  # Hz

aruco_detector:
  ros__parameters:
    namespace: "roborescue"
    robot_id: 1
    blue_box_id: 36
    yellow_box_id: 47  # TODO: Verificar este ID

aruco_navigator:
  ros__parameters:
    namespace: "roborescue"
    target: "blue_box"  # o "yellow_box"
    max_linear_speed: 0.5
    max_angular_speed: 1.0
    linear_p_gain: 0.6
    angular_p_gain: 1.5
    goal_tolerance: 0.15  # metros

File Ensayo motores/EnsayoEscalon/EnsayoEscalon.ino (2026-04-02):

#include <Arduino.h>

portMUX_TYPE mux = portMUX_INITIALIZER_UNLOCKED;

// ================================================================
//  CONFIGURACIÓN DE PINES 
// ================================================================
#define FL_PWM 13    
#define FL_DIR 25  
#define FL_ENC_A 16
#define FL_ENC_B 17

#define FR_PWM 33   
#define FR_DIR 32  
#define FR_ENC_A 26
#define FR_ENC_B 27

#define RL_PWM 18
#define RL_DIR 4
#define RL_ENC_A 22
#define RL_ENC_B 23

#define RR_PWM 21
#define RR_DIR 19
#define RR_ENC_A 34
#define RR_ENC_B 35

// Configuración PWM
const int freq = 1000;
const int resolution = 8;

// ================================================================
//  CONSTANTES DEL ROBOT Y MOTORES
// ================================================================
const float RADIO_RUEDA = 0.0325; 
const int PPR_MOTOR = 11;          
const int GEAR_RATIO = 34;         

// Resolución 4X confirmada
const int COUNTS_PER_REV = (PPR_MOTOR * GEAR_RATIO) * 4; 
const float rads_por_cuenta = (2.0f * PI) / (float)COUNTS_PER_REV;

// ================================================================
//  CONFIGURACIÓN DEL ENSAYO
// ================================================================
enum Motores { M_FL, M_FR, M_RL, M_RR };

// ---> CAMBIA ESTA VARIABLE PARA ELEGIR QUÉ MOTOR ENSAYAR <---
const Motores MOTOR_A_PROBAR = M_FL; 

const int PWM_ESCALON = 150;     
const unsigned long ventana_us = 40000;  //Tiempo de muestreo

// ================================================================
//  VARIABLES DE ESTADO Y TIEMPO
// ================================================================
volatile long cont_FL = 0, cont_FR = 0, cont_RL = 0, cont_RR = 0;
long prev_FL = 0, prev_FR = 0, prev_RL = 0, prev_RR = 0;

unsigned long lastWindowUs = 0;
unsigned long tiempoInicioEnsayo = 0;

int pwm_actual = 0;
int pwm_base = 0;
bool ensayo_terminado = false;

// ================================================================
//  INTERRUPCIONES (Resolución 4X Real Corregida)
// ================================================================
// ================================================================
//  INTERRUPCIONES (Resolución 4X Real Corregida e Invertida)
// ================================================================
// Canal A: ahora resta cuando son diferentes y suma cuando son iguales
void IRAM_ATTR isr_FL_A() { (digitalRead(FL_ENC_A) != digitalRead(FL_ENC_B)) ? cont_FL-- : cont_FL++; }
void IRAM_ATTR isr_FR_A() { (digitalRead(FR_ENC_A) != digitalRead(FR_ENC_B)) ? cont_FR-- : cont_FR++; }
void IRAM_ATTR isr_RL_A() { (digitalRead(RL_ENC_A) != digitalRead(RL_ENC_B)) ? cont_RL-- : cont_RL++; }
void IRAM_ATTR isr_RR_A() { (digitalRead(RR_ENC_A) != digitalRead(RR_ENC_B)) ? cont_RR-- : cont_RR++; }

// Canal B: ahora resta cuando son iguales y suma cuando son diferentes
void IRAM_ATTR isr_FL_B() { (digitalRead(FL_ENC_A) == digitalRead(FL_ENC_B)) ? cont_FL-- : cont_FL++; }
void IRAM_ATTR isr_FR_B() { (digitalRead(FR_ENC_A) == digitalRead(FR_ENC_B)) ? cont_FR-- : cont_FR++; }
void IRAM_ATTR isr_RL_B() { (digitalRead(RL_ENC_A) == digitalRead(RL_ENC_B)) ? cont_RL-- : cont_RL++; }
void IRAM_ATTR isr_RR_B() { (digitalRead(RR_ENC_A) == digitalRead(RR_ENC_B)) ? cont_RR-- : cont_RR++; }

// ================================================================
//  SETUP
// ================================================================
void setup() {
  Serial.begin(115200);
  delay(2000); 

  switch (MOTOR_A_PROBAR) {
    case M_FL: pwm_base = 89; break;
    case M_FR: pwm_base = 47; break;
    case M_RL: pwm_base = 84; break;
    case M_RR: pwm_base = 78; break;
  }
  
  Serial.println("Tiempo(s),PWM,rad/s,m/s");

  pinMode(FL_DIR, OUTPUT); digitalWrite(FL_DIR, LOW);  
  pinMode(RL_DIR, OUTPUT); digitalWrite(RL_DIR, LOW);  
  pinMode(FR_DIR, OUTPUT); digitalWrite(FR_DIR, HIGH); 
  pinMode(RR_DIR, OUTPUT); digitalWrite(RR_DIR, HIGH); 

  ledcAttach(FL_PWM, freq, resolution); ledcWrite(FL_PWM, 0);
  ledcAttach(FR_PWM, freq, resolution); ledcWrite(FR_PWM, 0);
  ledcAttach(RL_PWM, freq, resolution); ledcWrite(RL_PWM, 0);
  ledcAttach(RR_PWM, freq, resolution); ledcWrite(RR_PWM, 0);

  pinMode(FL_ENC_A, INPUT_PULLUP); pinMode(FL_ENC_B, INPUT_PULLUP);
  pinMode(FR_ENC_A, INPUT_PULLUP); pinMode(FR_ENC_B, INPUT_PULLUP);
  pinMode(RL_ENC_A, INPUT_PULLUP); pinMode(RL_ENC_B, INPUT_PULLUP);
  pinMode(RR_ENC_A, INPUT_PULLUP); pinMode(RR_ENC_B, INPUT_PULLUP);

  // Asignamos las interrupciones separadas
  attachInterrupt(digitalPinToInterrupt(FL_ENC_A), isr_FL_A, CHANGE);
  attachInterrupt(digitalPinToInterrupt(FL_ENC_B), isr_FL_B, CHANGE);
  
  attachInterrupt(digitalPinToInterrupt(FR_ENC_A), isr_FR_A, CHANGE);
  attachInterrupt(digitalPinToInterrupt(FR_ENC_B), isr_FR_B, CHANGE);
  
  attachInterrupt(digitalPinToInterrupt(RL_ENC_A), isr_RL_A, CHANGE);
  attachInterrupt(digitalPinToInterrupt(RL_ENC_B), isr_RL_B, CHANGE);
  
  attachInterrupt(digitalPinToInterrupt(RR_ENC_A), isr_RR_A, CHANGE);
  attachInterrupt(digitalPinToInterrupt(RR_ENC_B), isr_RR_B, CHANGE);

  delay(1000);
  tiempoInicioEnsayo = millis();
  lastWindowUs = micros();
}
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

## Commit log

2025-11-12 Boceto Caja
    Chasis con rejilla, Raspberry y ruedas omnidireccionales. En progreso.
    [Caja_Ardilla.SLDASM]
2025-11-13 Modelos de algunas piezas
    Modelos de la raspberry pi5 con disipador, lidar, drivers y motores
    [H-Bridge_L298N.stp, Pololu-25D-12V-21kgcm-DCmotor.SLDPRT, RASPBERRY_PI_5+cooler v2.3mf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]
2025-11-14 Caja Ardilla 2.0
    Segunda versión del modelaje 3D del robot, con motores, servo y batería.
    [Caja_Ardilla2.0.SLDASM]
2025-11-14 Caja Ardilla 3.0
    Tercera versión del modelado 3D del robot. Ruedas escaladas con diámetros aproximados.
    [Caja_Ardilla3.0.SLDASM]
2025-11-19 Inicio Modelado 3D
    Modelado del Chasis con algunos componentes: 4 ruedas omnidireccionales, 4 motores, la batería y el Raspberry. Aún en desarrollo
    [Caja_Ardilla.SLDASM, Caja_Ardilla2.0.SLDASM, Caja_Ardilla3.0.SLDASM]
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2025-11-21 Prototipo de garra paralela
    He encontrado este modelo de garra paralela que nos podría servir adaptándolo a lo que queremos
    [ARM MECHANISM N 20 motor 2.0.SLDPRT, ARM RIGHT 2.0 n 20 left.SLDPRT, ARM RIGHT 2.0 n 20 right.SLDPRT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]
2025-11-21 Añadidos dos prototipos más de garras
    He encontrado estos otros dos modelos que nos pueden servir de ejemplo
    [BASE GRIPPER URC 2.0 cassing upper.SLDPRT, BASE GRIPPER URC 2.0 cassing.SLDPRT, Gripper Iteration 3.SLDASM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]
2025-11-21 Chasis actualizado
    Nueva versión del chasis, con cara preparada para la garra y hueco para la seta de emergencia
    [Caja_Ardilla3.0.SLDASM, Chasis.SLDPRT]
2025-11-21 Garra
    Modelo de la garra escalado
    [Garra.SLDPRT]
2025-11-22 Escalado de la Garra Paralela
    He escalado 1 por 1 los archivos de la garra y he añadido dientes a las cremalleras para poder abrir más la pinza
    [ARM MECHANISM N 20 motor 2.0.SLDPRT, ARM RIGHT 2.0 n 20 left.SLDPRT, ARM RIGHT 2.0 n 20 right.SLDPRT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]
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2025-11-26 Avances 26-11-2025
    Actualización del tamaño del chasis, de la garra y creación de un nuevo chasis tipo ensamblaje con piezas preparadas para su impresión
    [ARM MECHANISM N 20 motor 2.0.SLDPRT, ARM RIGHT 2.0 n 20 left.SLDPRT, Caja_Ardilla3.0.SLDASM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]
2025-11-26 Prototipo de base para el chasis
    [Base.SLDPRT, Caja_Ardilla3.0.SLDASM, Chasis.SLDPRT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]
2025-11-27 Soportes de Motores
    Nuevos soportes para los motores de las ruedas.
    [Base.SLDPRT, Caja_Ardilla3.0.SLDASM, Motor v3.SLDPRT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]
2025-11-28 Add files via upload
    Prototipo para la base del chasis con soporte para los motores de las ruedas
    [Base_asembly.SLDASM, Prototipo_Base.SLDPRT, soporte rueda inferior.SLDPRT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]
2025-11-28 Garra con servo inacabada
    [Brazo derecho.SLDPRT, Brazo derecho2.SLDPRT, Brazo derecho3.SLDPRT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]
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2025-11-30 Garra Actualizada
    Garra modificada con el servo metido dentro
    [Bidirectional shoulder.SLDPRT, Bidirectional shoulder.STEP, Brazo derecho3.SLDPRT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]
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2025-12-03 Base con huecos para taquitos.
    He añadido dos archivos stl de la base.
    [Prototipo_Base2.STL, Taquitos_Base.STL]
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2025-12-09 Añadido 3mf de 10 taquitos para poder imprimirlos cuando hagan falta
    [10_Taquitos_Base_Imprimir.3mf]
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2025-12-10 Primera versión tornillo infinito
    [Prototipo_Base_Cuarto.STL, Tornillo_infinito.SLDPRT]
2025-12-11 Cambio de dimensiones pinza
    He aumentado la longitud de la pinza para que haya margen para que gire sin problema la caja de bellotas
    [ARM MECHANISM N 20 motor 2.0.SLDPRT, ARM RIGHT 2.0 n 20 left.SLDPRT, Brazo derecho3.SLDPRT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]
2025-12-11 Posible mecanismo de subida
    [Mecanismo.SLDASM, cremallera.SLDPRT, engranaje_up.SLDPRT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]
2025-12-12 Limpieza de garras sin usar
    [BASE GRIPPER URC 2.0 cassing upper.SLDPRT, BASE GRIPPER URC 2.0 cassing.SLDPRT, Base_asembly.SLDASM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]
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2025-12-12 Rueda escalada
    He hecho la rueda más pequeña y ahora coincide con la nuestra de 65mm de diámetro. Habría que modelar la pieza de unión entre el motor y la rueda
    [Caja_Ardilla3.0.SLDASM, Rueda.SLDPRT, engranaje_stl.STL]
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2025-12-13 Limpieza general de archivos repetidos
    [608RS.SLDPRT, ARM MECHANISM N 20 motor 2.0.SLDPRT, soporte rueda inferior.SLDPRT]
2025-12-16 Cosas garra y limpieza
    [10_Taquitos_Base_Imprimir.3mf, ARM MECHANISM N 20 motor 2.0.SLDPRT, ARM RIGHT 2.0 n 20 left.SLDPRT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]
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2025-12-17 Mecanismo rotatorio de la garra
    [ARM RIGHT 2.0 n 20 left.SLDPRT, Brazo derecho3.SLDPRT, Caja_Ardilla3.0.SLDASM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]
2025-12-19 Actualización modelo soporte de motor
    [soporte rueda inferior.SLDPRT, soporte rueda inferior.STL, soporte rueda inferior_prueba3.SLDPRT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]
2025-12-19 Pared modificada para nuevo soporte rueda
    [Pared.SLDPRT, Pared_V2.SLDPRT]
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2025-12-29 Create servomotor_hs311 - copia.SLDPRT
    [servomotor_hs311 - copia.SLDPRT]
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2026-01-03 Esquema eléctrico
    Esquema mejorado + documento describiendo el layout de los pines y lista de componentes electrónicos
    [EsquemaV3.kicad_sch, Mejora del esquema.kicad_sch]
2026-01-10 Ficheros del cursor de temperatura y del tablero
    Extraídos de la página oficial de Eurobot
    [cursor.stl, cursor.stp]
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2026-01-11 Base Arreglada
    [Base_back_cuarto_derecha.STL, Base_back_cuarto_izq.STL]
2026-01-20 Archivos stl techo robot
    [Techo.STL, Techo_Agujero.STL]
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2026-01-25 Garra terminada
    He creado el soporte del servo y hecho los agujeros para anclarlo a la garra
    [ARM MECHANISM N 20 motor 2.0.SLDPRT, Parte1 SoporteHS311.SLDPRT, Parte2 SoporteHS311.SLDPRT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]
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2026-01-29 Revert "???"
    This reverts commit 44c8b84941cd08232d8077316684439d46170613.
    [PasanteGarraIzquierda.3mf, PasanteGarraIzquierda.STL, PiezaGiratoriaRodamientoGarraIzq.3mf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]
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2026-01-31 Cambiar un error y añadir version pdf de la descripcion
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
